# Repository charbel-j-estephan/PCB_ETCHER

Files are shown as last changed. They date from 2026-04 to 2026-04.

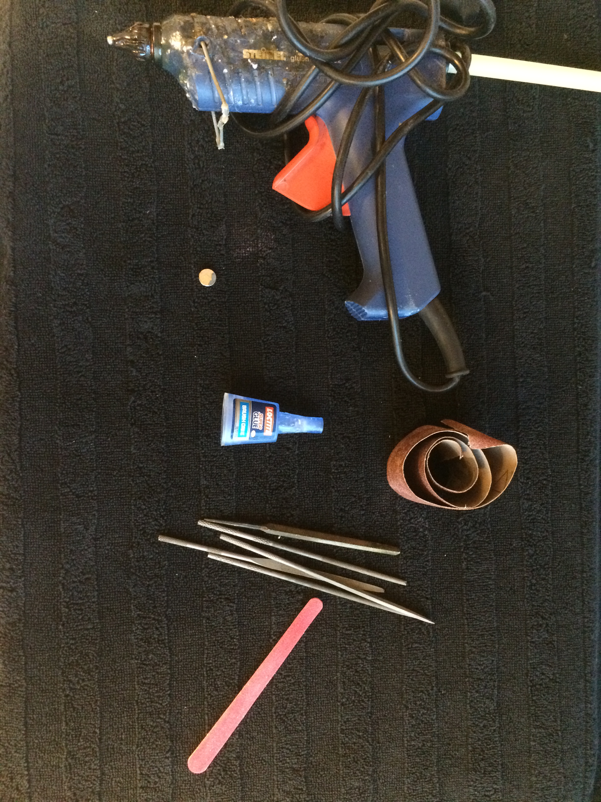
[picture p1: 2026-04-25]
3d prints/servo/images/IMG_0379.JPG

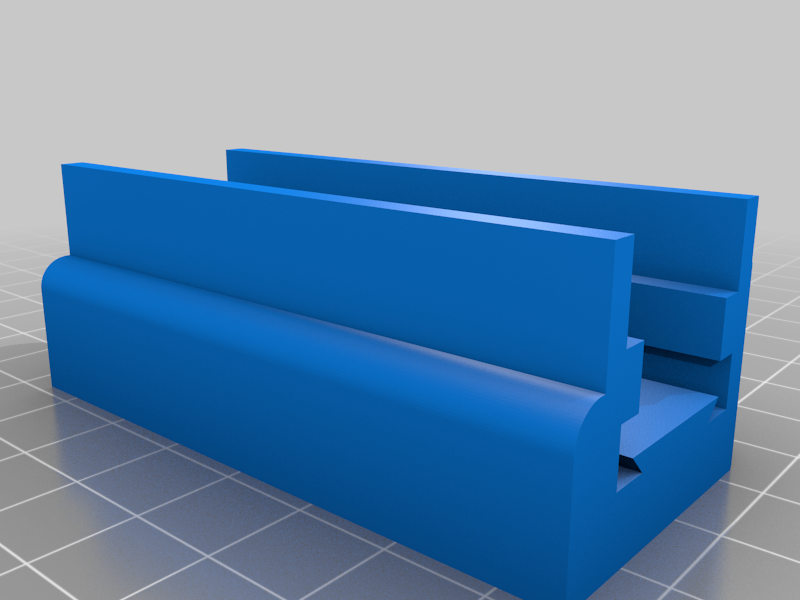
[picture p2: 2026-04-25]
3d prints/servo/images/e4eb49ccf6357d161828037bad2b64a9.png

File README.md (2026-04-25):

# PCB ETCHER

A high-precision automated system designed to convert Gerber files into physical PCB layouts using a **PIC16F877A** for motion control and an **ESP32** for cloud-based file management.

---

## 🚀 Overview
This project bridges the gap between digital PCB design and physical prototyping. It features a custom-built CNC chassis capable of **400 steps/mm precision**, utilizing a frame-based UART protocol for reliable data transfer between the web interface and the motor controllers.

## 🛠️ Technical Specifications

### Hardware
* **Main Controller:** PIC16F877A (Running with a **4MHz Crystal**)
* **Network Bridge:** ESP32 (Web Server & Handshake Protocol)
* **Motors:** NEMA 17 Steppers with T8 Lead Screws
* **Drivers:** L293D H-Bridge with 74HC04 Logic Inverters
* **Actuator:** SG90 Servo for Pen Lift (PWM controlled)
* **Display:** 16x2 LCD (Port E: RS=RE2, RW=RE1, E=RE0)

### Software & Firmware
* **Motion Logic:** Custom implementation of the **Bresenham Algorithm** for linear interpolation.
* **Communication:** UART @ 9600 Baud with a custom frame-based handshake protocol.
* **Microstepping:** Calibrated for 1/16 microstepping.
* **Logic:** * `1` = Pen Down (Writing)
  * `0` = Pen Up (Moving)

## 📂 Project Structure
As shown in the repository:
* `3d prints/` - STL files for the CNC chassis and motor mounts.
* `asm/` - PIC16F877A Assembly source code and firmware.
* `documentations/` - Datasheets, wiring diagrams, and project notes.
* `esp32_firmware_v8_1/` - ESP32 source code for the Wi-Fi bridge.
* `pcb-plotter-server/` - Web interface and Gerber processing logic.
* `simulations/` - Proteus and circuit simulation files.

## 📐 Calibration Details
| Parameter | Value |
| :--- | :--- |
| **Resolution** | 400 steps/mm |
| **Step Angle** | 1.8° |
| **Lead Screw Pitch** | 8mm |
| **Microstepping** | 1/16 |
| **Baud Rate** | 9600 |

## 🏗️ System Architecture
1. **Web UI:** Users upload Gerber files to the `pcb-plotter-server`.
2. **Data Processing:** The ESP32 processes the coordinates and initiates a handshake with the PIC.
3. **Motion Execution:** The PIC16F877A receives instructions and generates precisely timed pulses for the NEMA 17 motors using Assembly-optimized routines.
4. **Homing:** Integrated hardware homing ensures a consistent zero-point.

---

## 🤝 Contributing
Feel free to fork this repo and submit pull requests for any optimizations in the motion algorithm or UI.

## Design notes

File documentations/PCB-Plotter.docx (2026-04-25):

CNC PCB PLOTTER

Design, Firmware & Cloud-Integrated Motion Control

Micro-Controller Lab : PIC 16F877A

Charbel Estephan 20231222
Habib Bou Maroun 20223435

# Abstract

This report documents how to designed and built a CNC PCB plotter from scratch. The machine takes a Gerber file (the standard format that PCB manufacturers use) and draws the copper traces directly onto a blank copper board using a pen. The whole thing runs autonomously once you upload the file from a browser.

The system has three main parts talking to each other: A Python backend running on Google Cloud that converts the Gerber file into machine specific instruction set, an ESP32 that handles WiFi and the webpage, and a PIC16F877A microcontroller written in assembly that actually drives the stepper motors. The PIC is doing all the real-time work from running a Bresenham line algorithm in 24-bit integer arithmetic to generating step pulses at up to 1000 Hz, and maintaining the coordinate system. The motors run at 1/16 micro-stepping through A4988 driver modules, giving a resolution of 400 steps/mm on both axes.

# 1. Introduction

## 1.1 Why Build This

Getting a PCB made professionally takes at least a week and only makes sense if you order several at a time. On the other hand, doing toner transfer at home is messy. A plotter seemed like the right middle ground: it draws the resist mask directly onto the board under numeric control.

It is also a genuinely interesting engineering problem. To make it work you need motion control, embedded firmware, wireless communication, cloud deployment, and mechanical design all working together. Every single part of the stack is under direct control, which made debugging painful at times but also made it very educational.

## 1.2 Goals

A few concrete targets before starting:

- The machine should accept Gerber files because every PCB CAD tool exports Gerber.
- The working area should be at least 250 mm × 220 mm, large enough for most single-sided hobby boards.
- It should be controllable from a browser. No installing software, no USB cable required to start a job.
- Gerber parsing should not happen on the microcontroller. That keeps the embedded firmware small and lets me fix parser bugs without reflashing hardware.

# 2. System Architecture

The plotter is split into three layers, each running on a different processor. The split is not arbitrary, it follows the natural boundary between what needs to be fast, what needs to be smart, and what needs to be heavy.

## 2.1 The Three Layers

### Layer 1 — Cloud Backend (Python / Flask / Google Cloud Run)

Gerber parsing lives here. The backend is a Flask app running in a Docker container on Cloud Run. When the ESP32 uploads a Gerber file, the backend parses it, expands pad geometry into filled pen strokes, clamps everything to the machine's working envelope, and sends back a stream of 14-byte motion commands.

Why Cloud Parsing?
Gerber files can be hundreds of kilobytes, and building a robust Gerber parser in C on a memory-constrained embedded processor is a terrible idea. Python's regex handles the file in milliseconds no hardware involved.

### Layer 2 — Communication Hub (ESP32 / Arduino C++)

The ESP32 is the network interface. It hosts the web page, uploads Gerber to the cloud over HTTPS, fetches the motion commands back in chunks, and relays them one at a time to the PIC over a UART link. In essence it is a protocol translator: WiFi/TLS on one side, simple 9600-baud UART on the other.

### Layer 3 — Motion Controller (PIC16F877A / MPASM Assembly)

The PIC does the real-time heavy lifting. It receives ASCII motion frames, converts them to step counts, runs the Bresenham algorithm to generate coordinated XY pulses, drives the stepper driver modules, polls the limit switches during homing, and updates the LCD. Everything is written in MPASM assembly, because the PIC at 4 MHz has tight timing constraints and the arithmetic needs to be verified at the instruction level when things go wrong.

Layer | Processor | Language | Main job
1 - Backend | Cloud Run | Python / Flask | Gerber parsing, coordinate generation
2 - Hub | ESP32 | Arduino C++ | WiFi, TLS, UART bridge
3 - Motion | PIC16F877A @ 4 MHz | MPASM Assembly | Bresenham, step pulses, LCD display

## 2.2 How a Plot Job Flows

Here is what actually happens end-to-end when you press 'Start' in the browser:

- The user selects a Gerber file in the ESP32's web interface.
- The ESP32 opens a TLS connection to Cloud Run and streams the file as a chunked HTTP upload.
- Cloud Run parses the file, expands all pad geometry, clamps coordinates to 250×220 mm, and writes the result to a temp file. It returns a JSON ticket: {job_id, total_cmds, total_bytes}.
- The ESP32 then fetches the command stream in 4 kB slices via GET /fetch?job=…&offset=…
- Each 14-byte frame is forwarded to the PIC over UART2. The ESP32 waits for ACK before sending the next one.
- After the last frame, the ESP32 sends DELETE /job/<id> to clean up the temp file on the server.

# 3. Hardware Components

## 3.1 PIC16F877A — Motion Controller

The PIC16F877A is the motion controller. It drives the steppers, reads limit switches, handles UART communication with the ESP32, and runs the LCD. It is an 8-bit Harvard RISC processor running at 4 MHz deliberately underpowered by modern standards, which forces you to be intentional about every instruction you write.

## 3.2 ESP32 — Communication Hub

The ESP32 DevKit v1 handles all the networking. It runs at 240 MHz with 520 kB SRAM, supports 802.11 b/g/n WiFi natively, and has a proper TLS stack (Mbed TLS) baked into the SDK. It also has UART2 for the PIC link.

## 3.3 NEMA 17 17HS3401S — Stepper Motors

Both axes use a NEMA 17 17HS3401S bipolar stepper. This is effectively the standard motor for home-scale CNC and 3D printing (it is physically large enough to move a pen carriage smoothly, and supported by every driver, coupler, and mechanical mount on the market). The 17HS3401S specifically is a short-body, low-current variant which keeps heat manageable when the driver is set to around 1.3 A per phase.

Parameter | Value
Step angle | 1.8° (200 full steps/revolution)
Phase current (rated) | 1.3 A
Holding torque | 28 N·cm
Shaft | T8- screw
Body length | 34 mm

The T8 is an 8 mm diameter trapezoidal lead screw with a 4-start thread giving 8 mm of linear travel per revolution. Combined with the 200-step motor and 1/16 micro-stepping: (200 × 16) ÷ 8 = 400 steps per millimeter. That is 2.5 µm per micro-step on paper about 160× finer than the pen tip, so the electronics are never the limiting factor on print quality.

# 4. The Stepper Motor Driver — How It Actually Works

This section goes into more depth than the rest of the report because the stepper driver is the most misunderstood part of the system. Most descriptions of CNC projects say 'connect STEP and DIR to the driver and it works' which is true, but gives you no understanding of what the driver is doing or why the motor behaves the way it does. This section explains the full picture.

## 4.1 The Problem the Driver Solves

Stepper motors are driven by current, not voltage. The torque a stepper produces is proportional to the current flowing through its coils not to the voltage applied. If you just connect a 12V supply directly to the motor windings, the current would ramp up at a rate of V/L (voltage divided by winding inductance, typically 2–5 mH), quickly exceed the rated current, and saturate the iron core, destroying the motor or the driver or both.

The other problem is that generating micro-stepping waveforms in software on the PIC is not feasible. At 1/16 micro-stepping and 1000 Hz step rate, the PIC would need to switch four H-bridge transistors, regulate current on two coils simultaneously, and compute the correct sinusoidal current level — all at 16,000 times per second. At 4 MHz that is 250 instruction cycles per step. There is no room left for Bresenham, UART, or the LCD.

A dedicated driver IC solves both problems. It accepts simple STEP and DIR pulses from the PIC, handles all H-bridge switching and current regulation internally, and operates its power stage from 12V while presenting a 3–5V logic interface. The PIC just counts steps.

| The fundamental role of the driver: translate digital step pulses from a microcontroller running at logic levels into precisely regulated current waveforms in the motor coils at power levels the microcontroller could never handle directly.

## 4.2 Inside the A4988

The A4988 from Allegro Microsystems is a DMOS microstepping driver with built-in translator logic. It is the most commonly used stepper driver in desktop CNC and 3D printing equipment. Understanding it requires understanding five things that happen inside the chip simultaneously.

### 4.2.1 The Translator Logic

The translator is the block that takes STEP pulses and converts them into the correct H-bridge switching pattern. Every rising edge on the STEP pin advances an internal state machine by one position. The state machine drives two full H-bridges — one per motor phase — according to a predetermined sequence.

Without micro-stepping, the sequence follows the classic four-phase pattern (A+B+, A-B+, A-B-, A+B-). With 1/16 micro-stepping enabled, the translator instead steps through a 32-entry lookup table on each STEP pulse, outputting a different target current level for each phase at every position. This is completely invisible to the PIC — it just keeps pulsing STEP and the translator handles the rest.

### 4.2.2 The PWM Chopper — Current Regulation

The lookup table outputs a target current level, but something has to actually enforce that current in the real motor coil. That is what the PWM chopper does. It runs a continuous feedback loop at approximately 20–40 kHz:

- The H-bridge applies 12V across the motor coil. Current ramps up at a rate of V/L (roughly 2–4 A/ms for the 17HS3401S).
- A small sense resistor (R_sense, soldered on the breakout board) is in series with the coil. The voltage across it equals I × R_sense and is read by an internal comparator.
- When the sensed current reaches the target level from the lookup table, the comparator fires and the PWM latch cuts off the H-bridge.
- After a fixed off-time (set by external components, typically 20–40 µs), the bridge re-enables and the cycle repeats.

The net result is a sawtooth current waveform whose average value equals the target level from the table. The 12V supply charges the coil quickly and the chopper regulates the average — this is why the motor runs from 12V even though its rated voltage is only 2.8V. Higher supply voltage means faster current rise, which means more torque at speed.

| The fixed off-time chopper is the reason CNC motors run from a much higher voltage than their rated spec. The driver is not applying 12V DC to a 2.8V motor — it is using 12V to charge the coil inductance quickly, then chopping the current back to the rated level. The result is better high-speed torque compared to running at 2.8V directly.

### 4.2.4 The H-Bridge — How Current Direction Works

A bipolar stepper needs current to flow in both directions through each winding to complete full rotation. A single transistor cannot do this — you need an H-bridge, which is four switching elements arranged so current can flow either way:

+12V

[FET1] [FET3] ← high-side (P-channel DMOS)

+---M---+ ← motor winding between midpoints

[FET2] [FET4] ← low-side (N-channel DMOS)

GND / R_sense

Forward current: FET1 + FET4 ON, FET2 + FET3 OFF

Reverse current: FET3 + FET2 ON, FET1 + FET4 OFF

The A4988 contains two complete H-bridges — one for Phase A (coils 1A/1B) and one for Phase B (coils 2A/2B). The translator logic switches these bridges in the correct sequence as STEP pulses arrive. The PIC never needs to think about any of this.

## 4.3 Setting the Current — VREF Explained

This is the most important calibration step and the one most likely to go wrong if you do not understand what you are doing. The maximum phase current is set by a trim potentiometer on the breakout board, which sets a reference voltage on the VREF pin of the IC. The relationship is:

A4988 formula: I_max = VREF / (8 × R_sense)

A4988 module (R_sense = 0.068 Ω), target I = 1.1 A:

VREF = 1.1 × 8 × 0.068 = 0.598 V → set to ~0.6 V

To calibrate: power the board without the motor connected, touch a multimeter positive probe to the VREF test point (centre of the trim pot), negative to GND, and adjust until you reach the target voltage. Do not skip this step — VREF too high will cook the driver; too low and the motor misses steps under load.

| Important: always attach the small aluminium heatsink to the top of the IC before running at currents above about 0.5 A. At 1.1 A per phase the driver dissipates roughly 1.5–2 W. Without a heatsink the thermal protection trips at ~150°C junction temperature, causing random shutdown that looks like firmware bugs.

## 4.4 Micro-Stepping Mode Selection

The micro-stepping resolution is set by three logic pins: MS1, MS2, MS3. On the breakout board, pull-up resistors hold all three HIGH by default (1/16 mode). The truth table is:

MS1 | MS2 | MS3 | Mode | Steps/rev | Steps/mm on T8
LOW | LOW | LOW | Full step | 200 | 25
HIGH | LOW | LOW | Half step | 400 | 50
LOW | HIGH | LOW | Quarter step | 800 | 100
HIGH | HIGH | LOW | Eighth step | 1,600 | 200
HIGH | HIGH | HIGH | Sixteenth step | 3,200 | 400

In this project all three MS pins are left floating to their board pull-ups (all HIGH), so the driver is always in 1/16 mode. No wiring from the PIC to the MS pins is needed. The PIC firmware assumes 400 steps/mm at all times.

## 4.5 A4988 vs DRV8825 — Which One and When

I started the project with the A4988 during full-step testing and switched to the DRV8825 when moving to 1/16 micro-stepping. Both modules are pin-compatible so swapping them required zero firmware changes. The practical differences that affected this project:

Feature | A4988 | DRV8825 | Notes
Max phase current | 2.0 A | 2.5 A | Both fine at 1.1 A — DRV8825 has more headroom
Max micro-stepping | 1/16 | 1/32 | DRV8825 is a future upgrade path
Step pulse minimum | 1 µs | 1.9 µs | PIC generates ~4 µs pulses — both satisfied
Current formula | VREF/8Rs | VREF/2Rs | Must not confuse these when setting VREF
Mid-band noise | More | Less | DRV8825 runs noticeably quieter at 1/16
Cost | Cheaper | Slightly more | Small difference at these quantities

## 4.6 Wiring the Driver to the PIC

The interface between PIC and driver uses four wires: two per axis (STEP and DIR). Both the A4988 and DRV8825 accept 3–5.5V / 2.5–5.25V logic, so the PIC's 5V outputs connect directly with no level shifting needed.

Driver Pin | PIC Pin | Signal | Notes
STEP (X axis) | PORTB,0 | X_STEP | Each rising edge = one micro-step
DIR (X axis) | PORTB,1 | X_DIR | Set before first STEP pulse; hold for entire move
STEP (Y axis) | PORTB,2 | Y_STEP | Same as X
DIR (Y axis) | PORTB,3 | Y_DIR | Same as X
ENABLE | GND | ~ENA | Tie permanently LOW — always enabled
RESET | 5V | ~RST | Tie permanently HIGH — never reset mid-job
MS1/MS2/MS3 | (pull-up) | Mode | Left to board pull-ups → 1/16 mode, no PIC wiring needed
VMOT | 12V PSU | Power | 100 µF 35V electrolytic cap to GND required nearby
1A, 1B | Motor coil A | Phase A | Polarity sets forward direction
2A, 2B | Motor coil B | Phase B | Polarity sets forward direction

The 100 µF decoupling capacitor on VMOT is not optional. The chopper generates sharp current spikes each switching cycle; without the capacitor these produce voltage spikes on the supply rail that can exceed the driver's absolute maximum rating and destroy it. I learned this the hard way on the first driver module.

### Step Pulse Generation in Firmware

On the PIC side, each step is generated by a brief BSF/BCF pair on the PORTB pin:

; Generate one step pulse on the X axis

BSF PORTB, 0 ; STEP → HIGH (rising edge triggers step in driver)

NOP ; short hold — A4988 needs ≥1 µs, DRV8825 ≥1.9 µs

NOP ; at 4 MHz each NOP = 250 ns; four NOPs = 1 µs minimum

NOP

NOP

BCF PORTB, 0 ; STEP → LOW (ready for next pulse)

; After this, STEP_DELAY loop runs to set the inter-step gap (feed rate)

The DIR pin must be stable before the first STEP pulse. In the Bresenham implementation, XDIR_F and YDIR_F flags are set based on an explicit compare of target vs. current position before entering the motion loop — so the direction is locked in before any pulses are generated.

## 4.7 Why 1/16 Micro-Stepping Made Such a Difference

The upgrade from full-step to 1/16 micro-stepping was the single most impactful change in the entire project in terms of visible output quality. The differences were immediate and obvious:

- Diagonal lines: at full-step you can see a faint staircase pattern on 45-degree traces. At 1/16 they look perfectly straight.
- Noise: the motor went from a loud resonant whine to a soft hiss. The resonance frequency at full-step falls right in the audible range at typical CNC feed rates; micro-stepping shifts it high enough that the motor passes through it too quickly to excite it.
- Vibration: at full-step you can feel the table vibrating during a move. At 1/16 it is essentially smooth. This matters for line quality because vibration means pen wobble.

The cost is that the PIC has to generate 16× more step pulses for the same linear travel. At 40 mm/s and 400 steps/mm, that is 16,000 pulses per second. At 4 MHz, one pulse every 250 instruction cycles is tight but workable — the Bresenham inner loop plus step pulse plus minimum delay fits in that window with a small margin.

# 5. Firmware Architecture

## 5.1 PIC16F877A — MPASM Assembly

### 5.1.1 Main Loop

The PIC firmware is a single-threaded assembly program. After initialisation and homing it drops into a tight loop that repeats for every motion command:

MAIN

CALL RECEIVE_LINE ; wait for a 14-byte ASCII frame on UART

BTFSC ENDFLAG, 0 ; is it the 'END' marker?

GOTO PLOT_DONE ; yes → stop and print PLOT COMPLETE

CALL PARSE_AND_DISPLAY ; unpack X, Y, pen; update LCD

CALL EXECUTE_MOTION ; Bresenham + step pulses

CALL SEND_ACK ; send 'A' back to ESP32

GOTO MAIN

### 5.1.2 Peripheral Init (what each register actually does)

- TRISC = 0x81: makes RC7 (UART RX) an input and RC6 (TX) an output. The asymmetric pattern is because the USART overrides the TX TRIS bit automatically, but not RX.
- TXSTA = 0b00100100: selects asynchronous 8-bit mode, BRGH=1 for high-speed baud rate generation.
- SPBRG = 25: with BRGH=1 and Fosc=4 MHz, gives 4,000,000 ÷ (16×26) = 9,615 baud (+0.16% error — well within UART tolerance).
- RCSTA = 0b10010000: enables the serial port (SPEN) and the receiver (CREN).
- ADCON1 = 0x06: disables the ADC on all pins, reclaiming PORTA and PORTE as pure digital I/O.
- CMCON = 0x07: disables the comparators, which otherwise interfere with limit switch reads on PORTA.
- TRISA = 0b00001100: keeps PORTA,2 and PORTA,3 as inputs for the X and Y limit switches.

### 5.1.3 Memory Map (relevant registers)

Address | Name | What it holds
0x30–0x3D | BUF[14] | The current incoming ASCII frame
0x50–0x55 | XTGT / YTGT | Target position, 24-bit, 3 bytes each
0x56–0x5B | XCUR / YCUR | Current machine position, 24-bit
0x5C–0x64 | DX / DY / BERR | Bresenham deltas and error accumulator, 24-bit
0x70–0x72 | MULX/MULH/MULL | Result of the step conversion multiply
0x68–0x6A | XDIR_F / YDIR_F / DOM_FLAG | Direction and dominant-axis flags

## 5.2 The 24-Bit Bresenham Algorithm

This is the core of the motion controller. Coordinated XY motion requires that both axes reach their targets at the same time, tracing a straight line between start and end points. Bresenham's algorithm does this using only integer addition and subtraction — no floating point, no trigonometry, which is essential on a processor with no hardware multiplier.

DX = |x_target - x_current|

DY = |y_target - y_current|

if DX >= DY:

dominant = X, minor = Y

else:

dominant = Y, minor = X

BERR = D_dominant / 2 ← starting error (biased to centre)

loop D_dominant times:

step dominant axis

BERR -= D_minor

if BERR < 0:

step minor axis

BERR += D_dominant

The 24-bit implementation is needed because step counts at 1/16 micro-stepping reach up to 100,000 (250 mm × 400 steps/mm), which overflows 16-bit integers. Every arithmetic operation on the three-byte values requires explicit carry propagation. The critical pattern:

; Add two 24-bit numbers stored as (HI:MD:LO) byte triples

ADD24:

MOVF TMP3, W

ADDWF RES_LO, F ; add low bytes

BTFSC STATUS, C ; did it carry into middle?

INCF RES_MD, F ; yes → bump middle byte

BTFSC STATUS, Z ; did that INCF roll over to zero?

INCF RES_HI, F ; yes → bump high byte too

MOVF TMPL, W

ADDWF RES_MD, F

BTFSC STATUS, C

INCF RES_HI, F

MOVF TMPH, W

ADDWF RES_HI, F

RETURN

The double-check (BTFSC STATUS,C then BTFSC STATUS,Z) is the key insight. The first catches the carry from the ADDWF. The second catches the case where the INCF of the middle byte itself rolls from 0xFF to 0x00 — which sets the Zero flag, not the Carry flag. Missing this second check causes a carry loss bug that manifests as coordinates being exactly 65,536 steps short. I hit this bug and spent a long time finding it.

## 5.3 ESP32 State Machine

The ESP32 loops through states: IDLE → SENDING (upload to Cloud Run) → READING_JOB (parse ticket JSON) → FETCH_CONNECT / FETCH_BODY (get next chunk) → PLOT_CHUNK (forward frames to PIC) → WAITING_ACK (blocked on PIC response) → CLEANUP → DONE. Each TLS session is closed after one 4 kB chunk to avoid Cloud Run idle timeout.

## 5.4 Flask Backend

The backend is about 390 lines of Python. The three endpoints are POST /convert (parse Gerber, return job ticket), GET /fetch?job=&offset=&len= (serve a byte slice), and DELETE /job/<id> (clean up). The Gerber divisor is extracted at runtime from the %FSLAX/Y header: divisor = 10^(number of decimal digits). Final frame format: f"I{x:06d}{y:06d}{pen}" — 14 characters, always, asserted before return.

# 6. Communication Protocol

## 6.1 Frame Format

Every motion command is a 14-byte ASCII string terminated by a single LF:

I XXXXXX YYYYYY Z \n

I = 1 byte = start marker, always the literal character 'I'

XXXXXX = 6 bytes = X position in steps, zero-padded ASCII decimal

YYYYYY = 6 bytes = Y position in steps, zero-padded ASCII decimal

Z = 1 byte = pen state: '1' = down, '2' = up

\n = 1 byte = line feed terminator

End-of-stream: the literal string END\n

Example: I0012000005001\n

X = 1200 steps = 3.00 mm, Y = 500 steps = 1.25 mm, pen down

## 6.2 Why ASCII and Not Binary

An early version of the protocol used binary encoding: one command byte, two 16-bit little-endian coordinate fields, one ACK byte. It was about half the size on the wire. I replaced it because it was genuinely unpleasant to debug — a single dropped byte on a binary stream corrupts every subsequent frame silently, and diagnosing that on a 9600-baud logic analyser trace is not fun.

ASCII with a fixed start marker ('I') and newline terminator is self-synchronising. The PIC can always find the next valid frame by scanning for 'I' followed by 12 digits and a valid pen byte. At 9600 baud and roughly one command per millimetre of travel, the extra bytes cost nothing measurable — the link never even approaches saturation.

## 6.3 Flow Control

Strict stop-and-wait: the ESP32 sends one frame, then waits for the PIC's two-byte response (pen-state echo + 'A' for ACK, or 'R' for NAK / retransmit). The important thing is that this is applied against a streaming data source — the ESP32 has the next frame ready to write the moment ACK arrives, so from the motor's perspective successive frames arrive without any meaningful gap. This is what prevents ink blobs at corners. More detail in Section 8.1.

# 7. Gerber Processing Pipeline

## 7.1 What Is a Gerber File

Gerber (RS-274X) is the format PCB manufacturers use. It is a text file describing shapes using a small command set: FS (coordinate format declaration), MO (units), AD (aperture definition), and operation codes D01/D02/D03 (draw/move/flash). The first thing the parser does is read the FS header to determine the coordinate divisor, which varies between files:

FS header | Decimal digits | Divisor | Example: X100000 =
%FSLAX24Y24*% | 4 | 10,000 | 10.0 mm
%FSLAX36Y36*% | 6 | 1,000,000 | 0.1 mm
%FSLAX46Y46*% | 6 | 1,000,000 | 0.1 mm

Getting this wrong was one of my early bugs — the parser was using a hardcoded divisor of 10,000 when most modern Gerbers need 1,000,000. The board was drawn at 1/100th scale. The fix was extracting the divisor from the header at runtime using a regex.

## 7.2 Aperture Expansion

When the Gerber file places a pad (D03 command), the parser does not just draw a dot — it expands the pad shape into a series of filled pen strokes using a 0.2 mm raster step (half the 0.4 mm pen width). Three shapes are handled:

- Circles: boundary stroke + horizontal raster + vertical raster. Both raster directions ensure complete coverage even with a worn pen tip.
- Rectangles: double boundary pass (to sharpen edges) + both-axis raster fill.
- Obrounds (stadium pads): boundary along the exact curved outline + serpentine fill within the stadium shape.

## 7.3 Coordinate Output

After all coordinates are collected: translate so the minimum corner sits at (0,0), mirror X if needed for copper-side-up drawing, add a 2 mm safety margin on both axes, then multiply by 400 to get integer step counts. The server also enforces a MAX_X_MM = 250 / MAX_Y_MM = 220 hard limit and returns HTTP 400 if the board is too large, with a message the web UI shows directly to the user.

# 8. Bugs and How I Fixed Them

This section is probably the most useful part of the report from a technical understanding perspective. These are the significant bugs I found and fixed during development. In each case I describe what was happening, why it was happening, and exactly what changed.

## 8.1 Ink Blobs at Every Corner

Symptom: every polygon corner on the drawn output had a small but visible ink blob, as if the pen had rested on the board for a moment before changing direction — because it had.

Root cause: the original protocol was strict stop-and-wait. The ESP32 sent a command, the PIC executed it from a standstill, the motor stopped completely, the PIC replied DONE, and only then did the ESP32 prepare and send the next command. Every direction change caused a full decelerate-halt-accelerate cycle, giving the pen a fraction of a second to sit stationary on the board and transfer extra ink via capillary action.

Fix: the protocol was redesigned so the ESP32 has the next frame already waiting in its UART transmit FIFO by the time the PIC's ACK arrives. Because 9600 baud transmission is fast relative to motor motion, the PIC receives the next command before the motor has fully stopped. From the motor's perspective, successive frames are continuous. The blobs disappeared completely.

## 8.2 24-Bit Carry Loss (the Hard One)

Symptom: plots of boards taller than about 163 mm would fail near the top. The Y carriage would stop 65,536 steps short of its target, crash into the mechanical end stop, and the plot would halt.

Root cause: 163 mm × 400 steps/mm = 65,200 steps, which is just under the 16-bit limit (65,535). Any Y coordinate above that required the middle byte of the 24-bit step count to roll over from 0xFF to 0x00. When that INCF executes, it sets the Zero flag — not the Carry flag — on the PIC. My carry propagation code only checked STATUS,C, so the carry into the high byte was silently dropped. Every Y coordinate above 163 mm was calculated as exactly 65,536 steps too small.

Fix: added a second check after every middle-byte INCF:

BTFSC STATUS, C ; carry from the previous ADDWF?

INCF MULH, F ; yes → increment middle byte

BTFSC STATUS, Z ; did that INCF roll MULH to 0x00?

INCF MULX, F ; yes → carry must propagate to high byte

This second BTFSC STATUS,Z / INCF pair is the bit I was missing everywhere. After adding it consistently to all 24-bit arithmetic blocks, the full coordinate range worked correctly.

## 8.3 Multiply-by-25 Was Multiply-by-5

Symptom: with the full-step firmware (25 steps/mm), every move was exactly 1/5 of the commanded distance. Commanding 100 mm produced 20 mm of travel.

Root cause: the shift-add multiplier for 25 (binary 11001) was missing the 8× shift term. The routine was computing 16× + 1× = 17×, and a second bug made it actually compute 4× + 1× = 5×. Fix: rewrote the routine from scratch against binary 11001 (bits 0, 3, 4), verified against Python for all inputs 0–65,535.

## 8.4 MUL8×16 High-Byte Corruption

Symptom: after the ×25 fix, moves over ~50 mm overshot by seemingly random amounts. Root cause: the carry-propagation in the multiplier used ADDLW to add 1 to W before adding to the high byte. ADDLW modifies W — so on the next iteration, W no longer held the multiplier byte as expected. Fix: replaced ADDLW/ADDWF with INCF (which never touches W), and added an explicit MOVF to reload the multiplier byte before each ADDWF.

## 8.5 Gerber Divisor (Drawings 100× Too Small)

Symptom: first real Gerber file drawn at 1/100th scale — the layout was recognisable but tiny. Root cause: hardcoded divisor of 10,000; the file used %FSLAX46Y46% which needs 1,000,000. Fix: runtime regex extraction of divisor = 10^(decimal field width) from the FS header.

## 8.6 Bresenham Direction Regression

Symptom: a brief firmware revision drew a mirror image along one axis. Root cause: tried to determine direction from the borrow flag of a 16-bit subtraction done as two 8-bit subtracts. Borrow does not propagate to the global carry bit correctly in this arrangement. Fix: reverted to explicit compare of target vs. current position before the loop, storing results in XDIR_F / YDIR_F flags. More readable and provably correct.

# 9. Testing and Validation

## 9.1 Proteus Simulation

Every significant firmware revision was run in Proteus before being flashed to real hardware. The simulation gives cycle-exact behaviour: the HD44780 virtual module shows the LCD output character-by-character, the virtual UART terminal lets you see exactly what bytes the PIC is receiving and transmitting, and logic analysers on PORTB show the actual step and direction pulses. About 80% of the bugs in Section 8 were found and fixed in simulation — not on hardware.

## 9.2 Step Calibration

Physical calibration: command exactly 100 mm in X and Y against a printed ruler. With 400 steps/mm and the T8 lead screw, the measured travel is within 0.1 mm of the commanded value. This confirms the firmware conversion constants are correct and the lead screw geometry matches the assumed 8 mm/rev lead.

## 9.3 End-to-End Plot Trials

Two regression test files: test_square.gbr (30×30 mm square with circular pads at corners — tests aperture expansion and corner motion) and test.gbr (complex trace pattern with diagonals, obrounds, overlapping polygons). Final validation involved drawing on copper-clad stock with resist-pen ink, etching in ferric chloride, inspecting under magnification, and testing trace continuity with a multimeter.

# 10. Final Specifications

## 10.1 Electrical

Parameter | Value
Motor supply | 12 V DC
Logic supply | 5 V DC (regulated from 12 V)
ESP32 supply | 5 V (on-board linear regulator)
Stepper phase current | ~1.1 A per phase (A4988 VREF ≈ 0.60 V)
UART (ESP32 ↔ PIC) | 9,600 baud, 8N1
WiFi | 2.4 GHz 802.11 b/g/n, WPA2-PSK

## 10.2 Mechanical

Parameter | Value
Work envelope | 250 mm (X) × 220 mm (Y)
Pen tip | 0.4 mm diameter
Raster fill step | 0.2 mm (half pen width)
Safety margin | 2 mm from origin on both axes
Homing | Micro-switch limits on PORTA,2 (X) and PORTA,3 (Y)
Frame material | 3D-printed PLA, 0.2 mm layers, 40% infill

## 10.3 Motion and Resolution

Parameter | Value
Step angle | 1.8° (200 full steps/revolution)
Lead-screw lead | 8 mm/revolution (T8, 4-start)
Micro-step resolution | 400 steps/mm at 1/16 (2.5 µm/step)
Step rate (calibrated) | 1,000 Hz
Feed rate (calibrated) | 2.5 mm/s linear (= 1000 Hz ÷ 400 steps/mm)
Max step count (X) | 100,000 steps (24-bit)
Max step count (Y) | 88,000 steps (24-bit)

# 11. Conclusion

## 11.1 What Was Achieved

The machine works. You can take a Gerber file from KiCad or any other standard PCB tool, upload it through the browser, and the plotter draws it onto copper-clad stock without any further intervention. Line quality is good — corners are clean, diagonals are smooth, and pads are properly filled. All the design goals from Section 1.2 are met.

## 11.2 Things I Would Do Differently

The biggest thing I would change is the communication architecture between the ESP32 and PIC. Using a higher baud rate — 115,200 instead of 9,600 — would allow tighter ACK-response loops and potentially higher feed rates without any firmware complexity cost. I stayed at 9,600 because it was the working value and changing it mid-project felt risky, but in hindsight it is an easy upgrade.

I would also add a proper velocity profile — ramp up from zero, hold constant speed, ramp down before a stop. Right now the motor accelerates instantly from zero, which works but causes occasional missed steps on long diagonal moves that start at full speed. This requires a small look-ahead buffer and is doable in assembly.

# Appendix A — Complete Pin Assignments

## A.1 PIC16F877A

Pin | Port | Dir | Signal | Connected to
33 | PORTB,0 | Out | X_STEP | A4988/DRV8825 STEP (X axis)
34 | PORTB,1 | Out | X_DIR | A4988/DRV8825 DIR (X axis)
35 | PORTB,2 | Out | Y_STEP | A4988/DRV8825 STEP (Y axis)
36 | PORTB,3 | Out | Y_DIR | A4988/DRV8825 DIR (Y axis)
4 | PORTA,2 | In | LIM_X | X limit switch, pull-down, active high
5 | PORTA,3 | In | LIM_Y | Y limit switch, pull-down, active high
25 | PORTC,6 | Out | UART TX | ESP32 GPIO16 (UART2 RX)
26 | PORTC,7 | In | UART RX | ESP32 GPIO17 (UART2 TX)
19–30 | PORTD,0–7 | Out | LCD D0–D7 | HD44780 data bus (8-bit mode)
8 | PORTE,0 | Out | LCD E | HD44780 Enable
9 | PORTE,1 | Out | LCD RW | HD44780 R/W (write only)
10 | PORTE,2 | Out | LCD RS | HD44780 Register Select

## A.2 ESP32 DevKit v1

GPIO | Dir | Signal | Connected to
GPIO16 | In | UART2 RX | PIC PORTC,6 (TX)
GPIO17 | Out | UART2 TX | PIC PORTC,7 (RX)
GPIO23 | Out | Servo PWM | SG90 continuous-rotation servo signal
GND | Pwr | Ground | Common ground with PIC and driver modules

# Appendix B — Firmware Constants

Constant | Value | Where | What it controls
STEPS_PER_MM | 400 | PIC | Steps per mm at 1/16 micro-stepping
SPBRG | 25 | PIC | UART baud rate divisor (→ 9615 baud at 4 MHz)
STEP_DELAY | 1 ms | PIC | Inter-step gap; sets feed rate
MAX_STEPS | 100,000 | PIC | Hard coordinate clamp in firmware
SERVO_STOP | 95 | ESP32 | PWM value that stops the SG90 (calibrate per unit)
SERVO_CW_SPEED | 110 | ESP32 | Pen-UP spin speed
SERVO_CCW_SPEED | 70 | ESP32 | Pen-DOWN spin speed
SERVO_MOVE_MS | 400 | ESP32 | Time to spin between pen states (ms)
ACK_TIMEOUT_MS | 60,000 | ESP32 | Max wait for PIC ACK before error
FETCH_CHUNK_SIZE | 4,096 | ESP32 | Bytes per /fetch request (~270 frames)
MAX_X_MM | 250 | Flask | Work envelope X limit
MAX_Y_MM | 220 | Flask | Work envelope Y limit
FILL_STEP | 0.2 | Flask | Pad raster step in mm
MIRROR_X | True | Flask | Mirror X for copper-side-up plotting

# Appendix C — End-to-End Frame Example

This traces one motion command from Gerber file all the way to physical motor pulses, to show how all the layers connect.

### Gerber input

%FSLAX46Y46*% ; divisor = 1,000,000

%MOMM*% ; metric

X100000Y050000D01* ; raw coords: X=0.10 mm, Y=0.05 mm, pen down

### Flask processing

x_mm = 100000 / 1,000,000 = 0.10 mm

y_mm = 50000 / 1,000,000 = 0.05 mm

Add 2mm margin: x = 2.10 mm, y = 2.05 mm

Convert to steps: x = 2.10 × 400 = 840, y = 2.05 × 400 = 820

pen = '1' (D01 = draw)

Output frame: I0008400008201\n

### ESP32 transmission

Serial2.write("I0008400008201\n", 15);

// 15 bytes at 9600 baud → transmission takes ~15.6 ms

// ESP32 transitions to WAITING_ACK

### PIC reception and motion

RECEIVE_LINE: BUF = ['I','0','0','0','8','4','0','0','0','8','2','0','1','\n']

Validation: start='I' ✓ digits ✓ pen='1' ✓

XTGT = 840, YTGT = 820, PENVAL = '1' (pen down)

EXECUTE_MOTION:

Assume previous position was (0, 0)

DX = 840, DY = 820 → dominant axis = X (840 > 820)

Bresenham runs 840 iterations:

X steps every iteration (840 total)

Y steps when error underflows (820 total)

At 1000 Hz: ~840 ms of motion

SEND_ACK: TX → '1' (pen state echo), 'A' (acknowledge)

### ACK received

ESP32 sees '1' → updates servo state, sees 'A' → returns to PLOT_CHUNK and sends the next frame. Total round-trip dominated by motion time. UART overhead is under 2% of total command time.

CNC PCB Plotter — Engineering Report | Charbel Estephan & Habib Bou Maroun

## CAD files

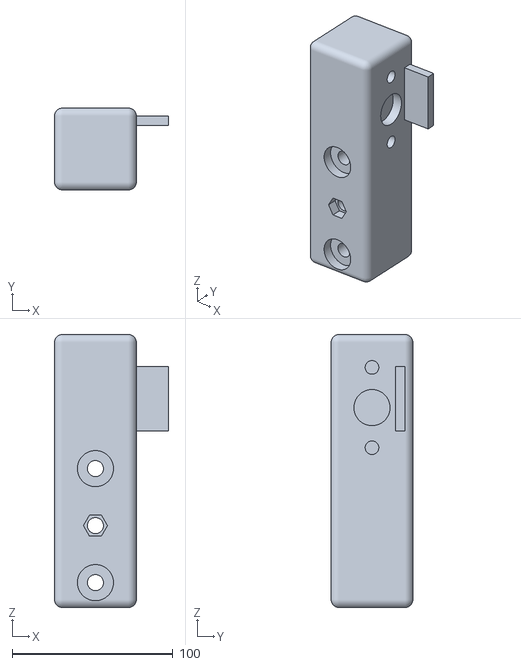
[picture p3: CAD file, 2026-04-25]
3d prints/2-Axis CNC - 5513594/files/Y-Axis_Carriage_W-O_Motor.stl
71.0 x 51.0 x 170.0

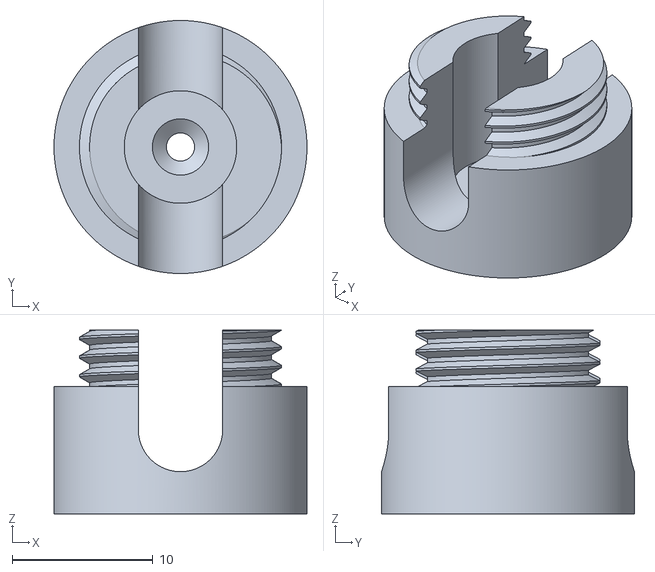
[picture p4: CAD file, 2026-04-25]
3d prints/cable holder/WL_D6.0mm_Bottom.stl
18.0 x 18.0 x 13.1

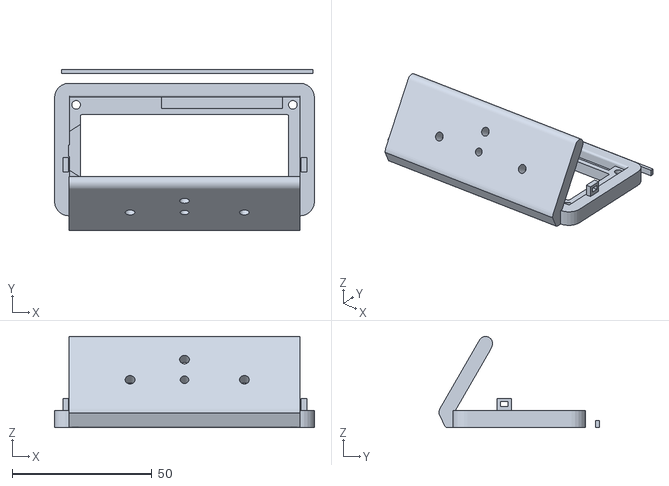
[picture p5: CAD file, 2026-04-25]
3d prints/lcd holder/files/LCD_Screen_Stand_v2.stl
92.9 x 57.4 x 32.6

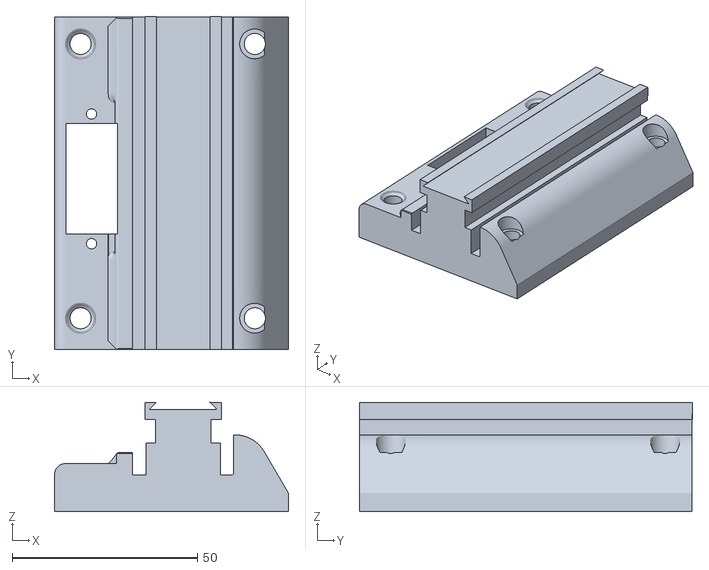
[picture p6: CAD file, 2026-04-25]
3d prints/servo/files/base_v2.0_servo_HS-85MG.stl
63.1 x 89.8 x 29.5

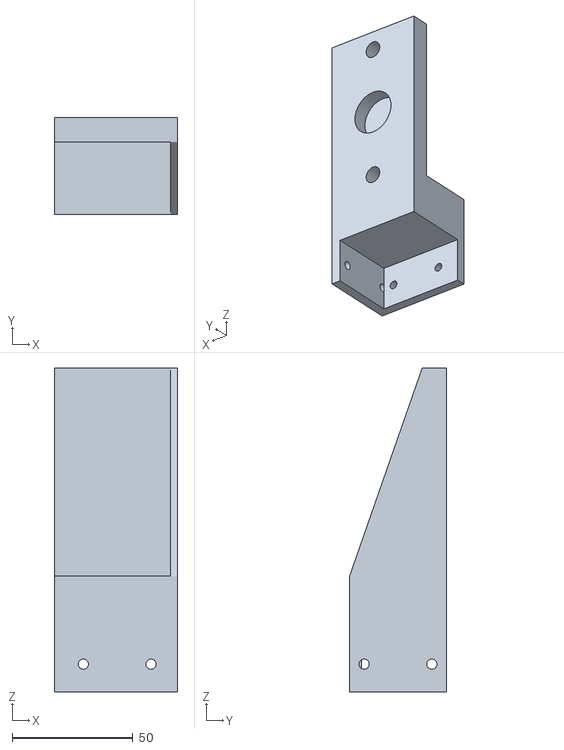
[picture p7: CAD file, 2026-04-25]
3d prints/2-Axis CNC - 5513594/files/Y-Axis_End.stl
51.0 x 40.0 x 134.0

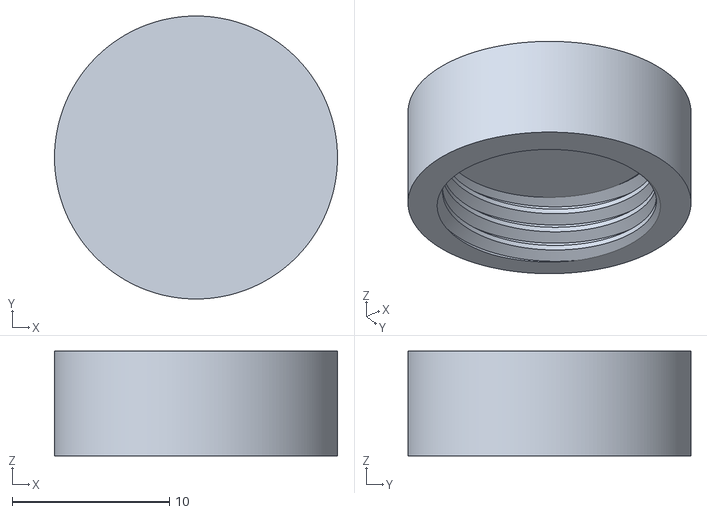
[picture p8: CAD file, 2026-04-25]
3d prints/cable holder/WL_D6.0mm_Top_Smooth.stl
18.0 x 18.0 x 6.67

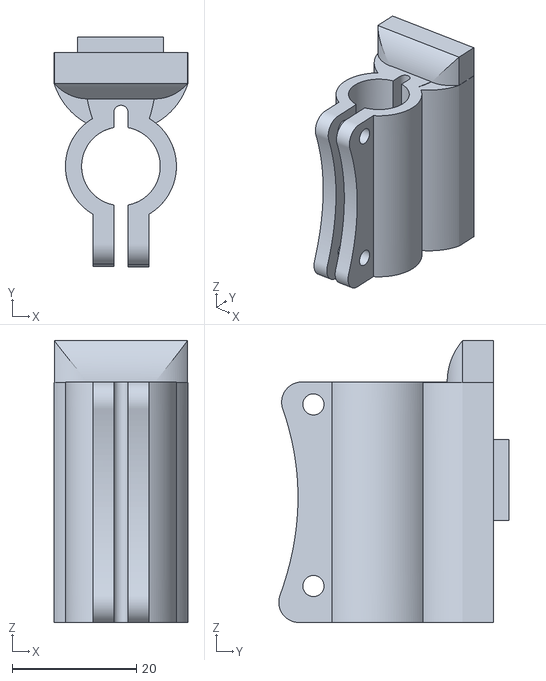
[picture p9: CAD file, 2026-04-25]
3d prints/servo/files/Pen_Mount_v2.0_HS-85MG_12mm_Magnets.stl
21.6 x 37.1 x 45.4

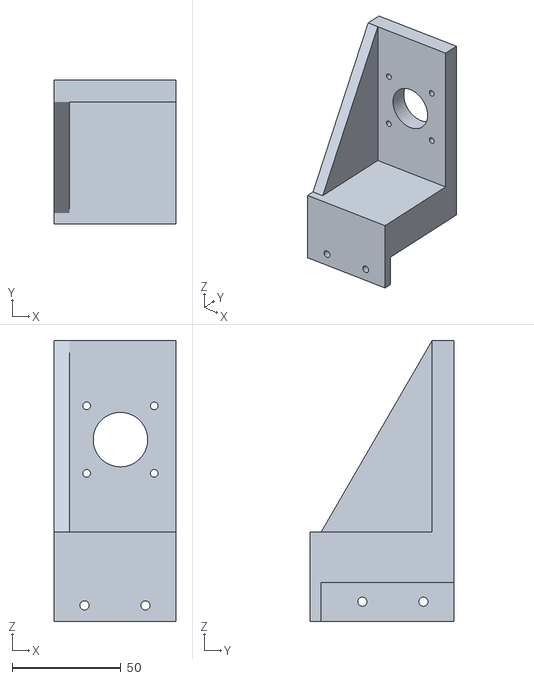
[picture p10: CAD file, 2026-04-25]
3d prints/2-Axis CNC - 5513594/files/Stepper_Motor_Mount.stl
56.0 x 66.0 x 129.0

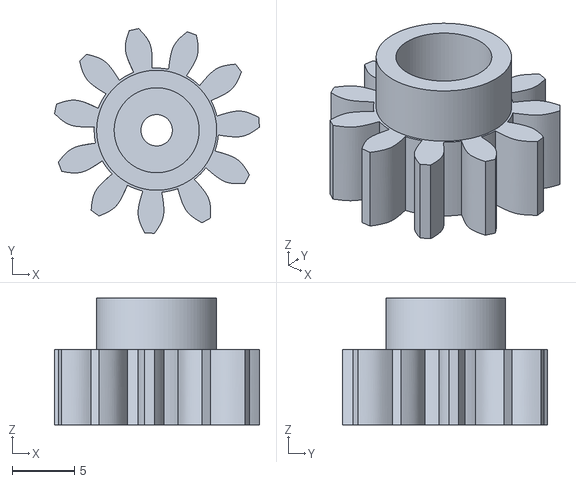
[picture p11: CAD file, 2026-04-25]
3d prints/servo/files/Gear.stl
16.5 x 16.5 x 10.2

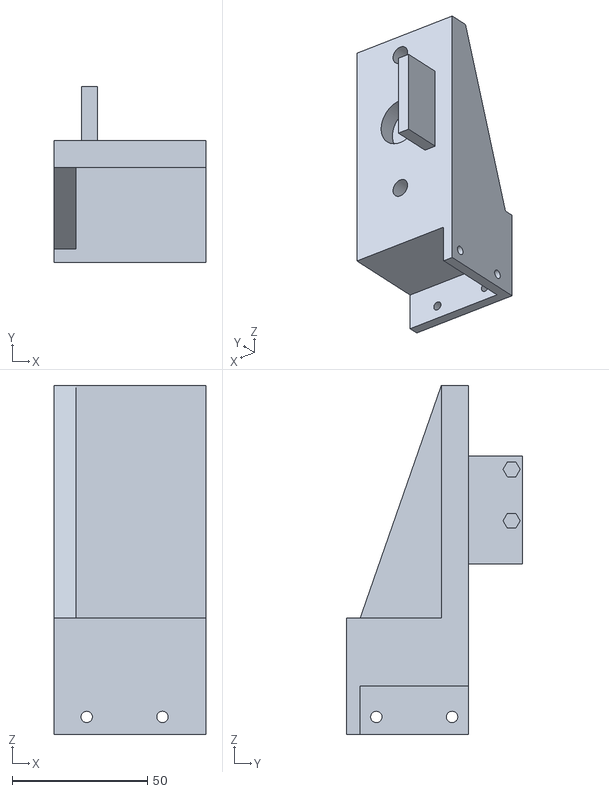
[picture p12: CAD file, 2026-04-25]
3d prints/2-Axis CNC - 5513594/files/Y-Axis_End_2.stl
56.0 x 65.0 x 129.0

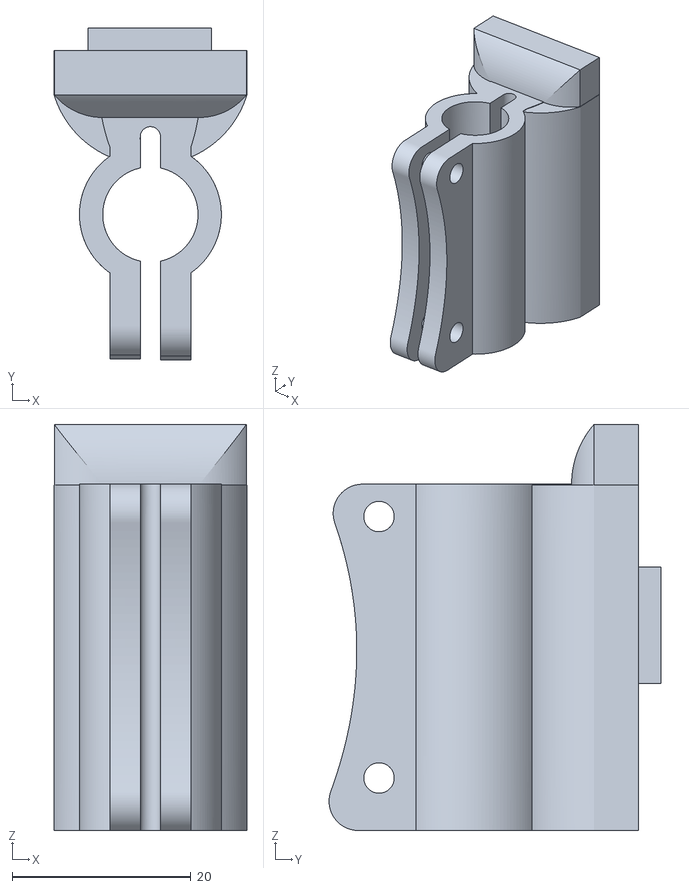
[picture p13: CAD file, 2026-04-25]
3d prints/servo/files/Pen.stl
21.6 x 37.1 x 45.4

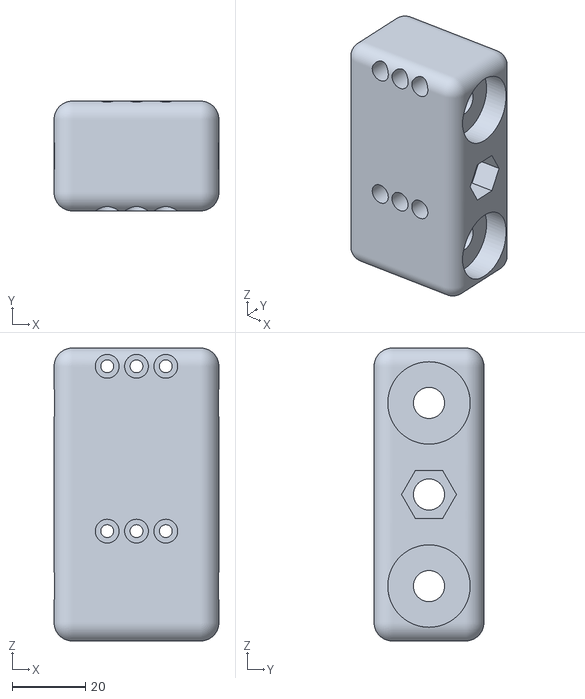
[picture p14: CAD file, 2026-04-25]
3d prints/2-Axis CNC - 5513594/files/Laser_Attachment.stl
45.0 x 30.0 x 80.0

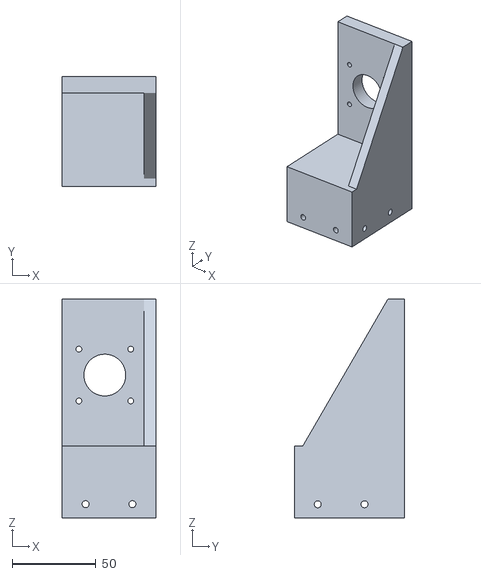
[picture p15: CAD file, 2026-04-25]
3d prints/2-Axis CNC - 5513594/files/Stepper_Motor_Mount_2.stl
56.0 x 66.0 x 131.0

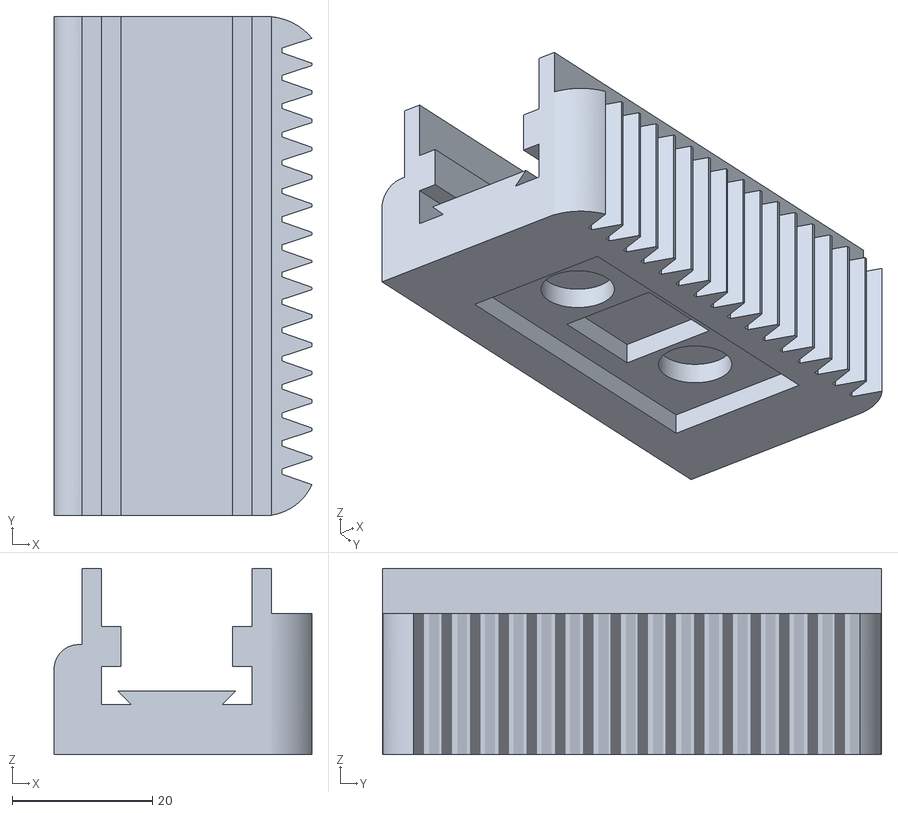
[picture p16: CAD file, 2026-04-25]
3d prints/servo/files/New_Rail.stl
36.7 x 71.0 x 26.5

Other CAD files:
3d prints/servo/files/base.stl
3d prints/2-Axis CNC - 5513594/files/Y-Axis_Carriage_W_Motor.stl
3d prints/servo/files/Rail_v2.0_Servo_HS-85MG_12mm_magnet.stl
3d prints/servo/files/Gear_v2.0_Servo_HS-85MG.stl

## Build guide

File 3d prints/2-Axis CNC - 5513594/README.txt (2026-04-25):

2-Axis CNC by Paragon427 on Thingiverse: https://www.thingiverse.com/thing:5513594

Summary:
I created a 2-Axis CNC to be used as a laser cutter.Here is a link to the instrucable with instructions on assembly and parts needed : https://www.instructables.com/Budget-2-Axis-CNC-Build/I designed this machine with a low budget in mind. I used 20% infill for all printed parts and supports on the pieces with overhangs.

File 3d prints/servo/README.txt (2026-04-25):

Plotter Z axis by Spiritus on Thingiverse: https://www.thingiverse.com/thing:1341835

Summary:
⦁   4x neodym magnets 10mm... V2.0 is 12mm magnets.⦁   Mini 9 gram servo...Or... " V2.0 ( Servo: HS-85MG ) "⦁   servo arm to the gearwheel⦁   glue⦁   Mineral oil or some kind of lubricant⦁   sandpaper + files

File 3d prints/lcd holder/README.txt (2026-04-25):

16x2 LCD Display Stand by Thejustintimer on Thingiverse: https://www.thingiverse.com/thing:1904529

Summary:
After trying to mount my lcd screen rigidly and upright I decided to add a stand to the original design by deisterhold. This design features a 30 degree incline and a method of securing the screen in place which requires no supports. This method uses a bar to slide into position as I'm sure you can work out from the included files.

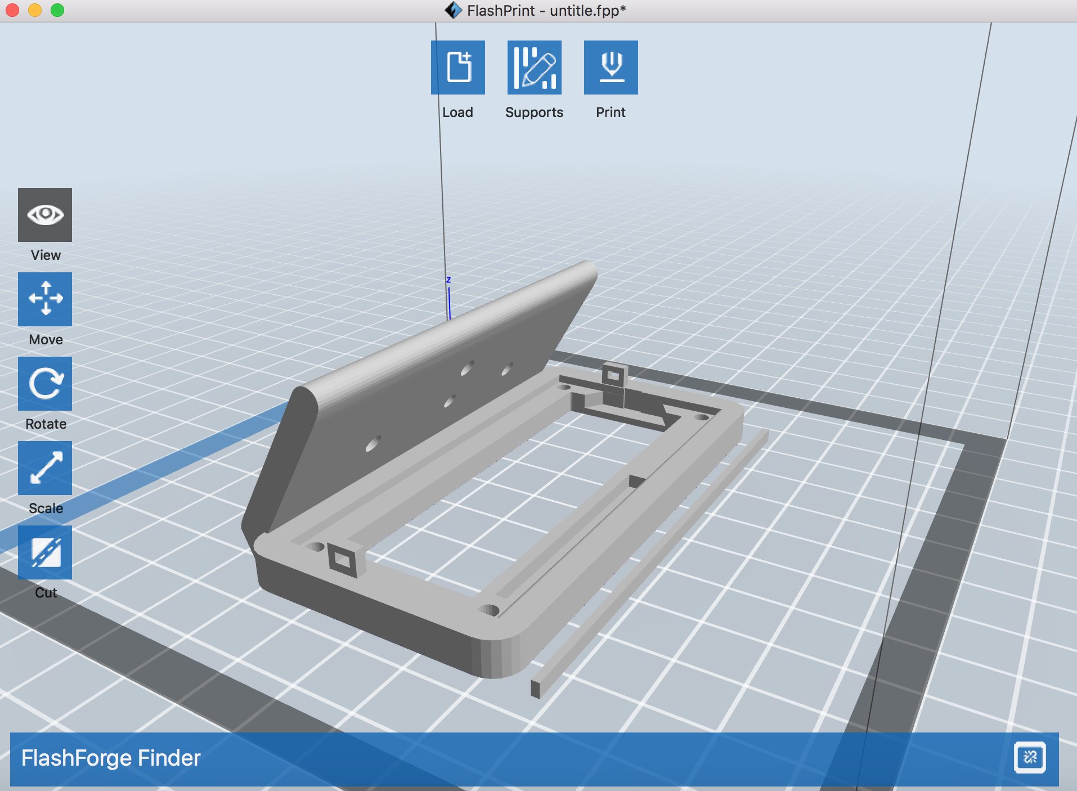
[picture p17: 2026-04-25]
3d prints/lcd holder/images/Screen_Shot_2016-11-21_at_5.59.00_PM.png

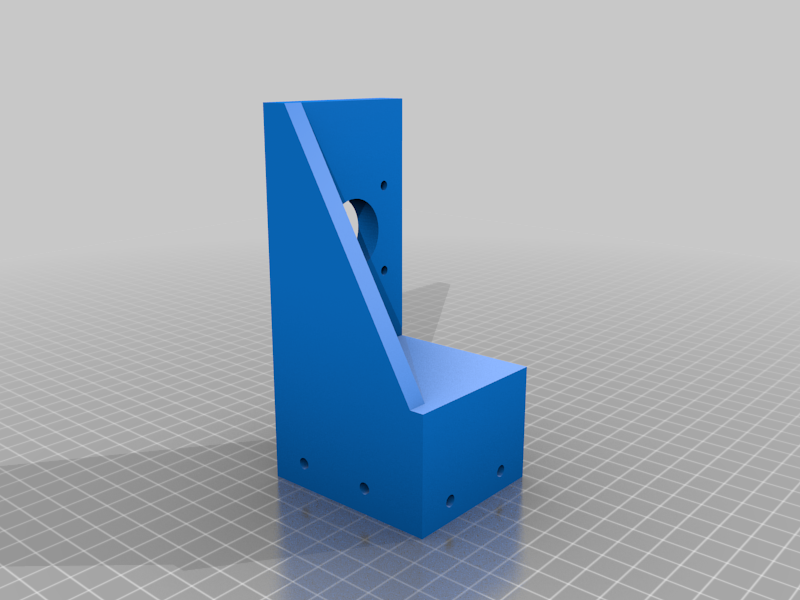
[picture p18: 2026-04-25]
3d prints/2-Axis CNC - 5513594/images/e388011e-67d6-48d2-9319-ce4bdc6c1ae6.png

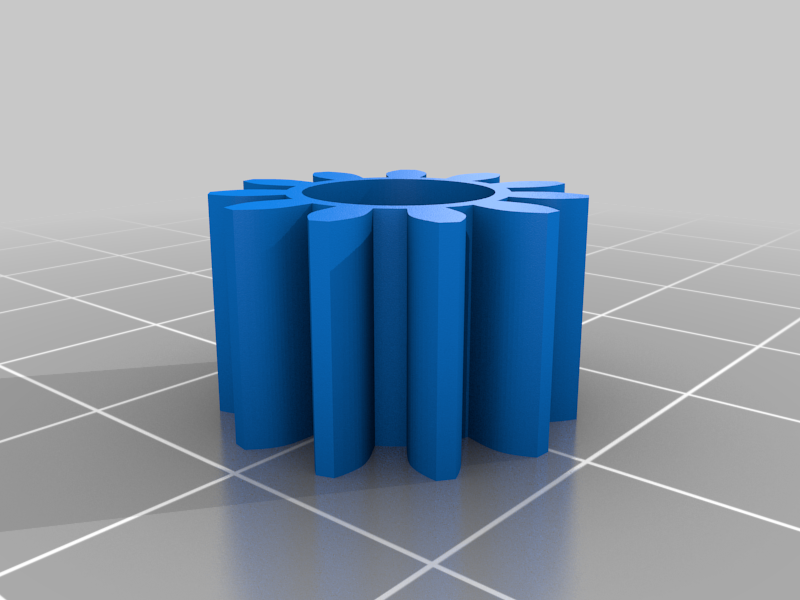
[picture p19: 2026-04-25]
3d prints/servo/images/7f779bc755f02488236bcb452ff18de2.png

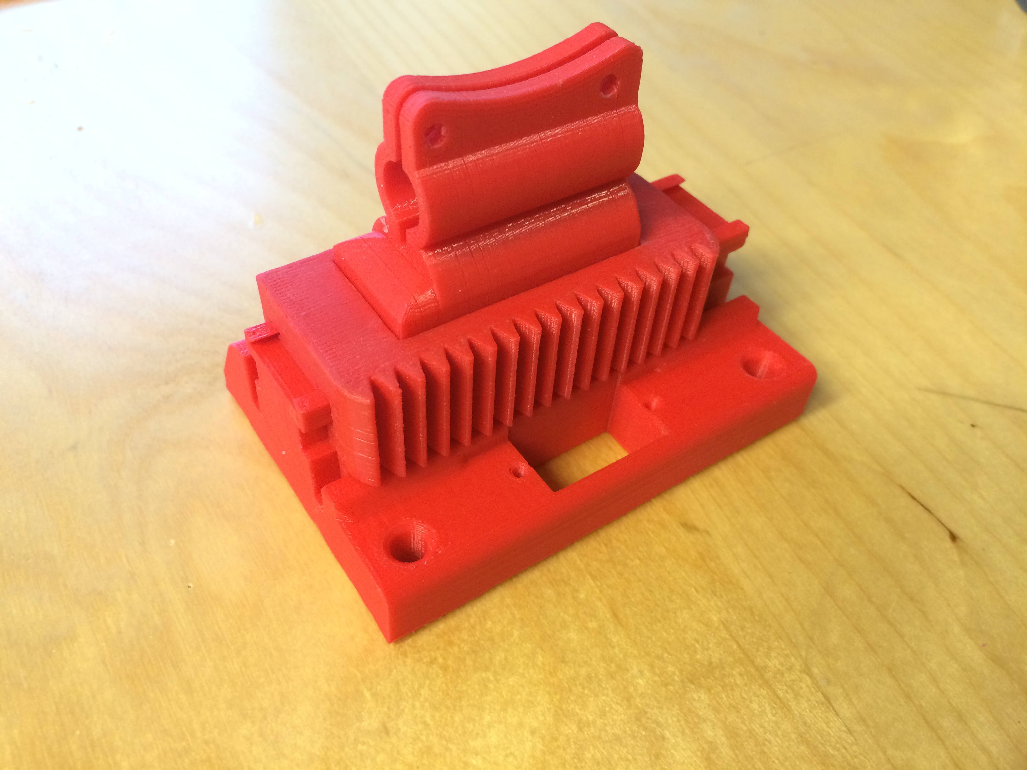
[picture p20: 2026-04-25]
3d prints/servo/images/IMG_0370.JPG

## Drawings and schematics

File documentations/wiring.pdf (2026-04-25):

R2

U2

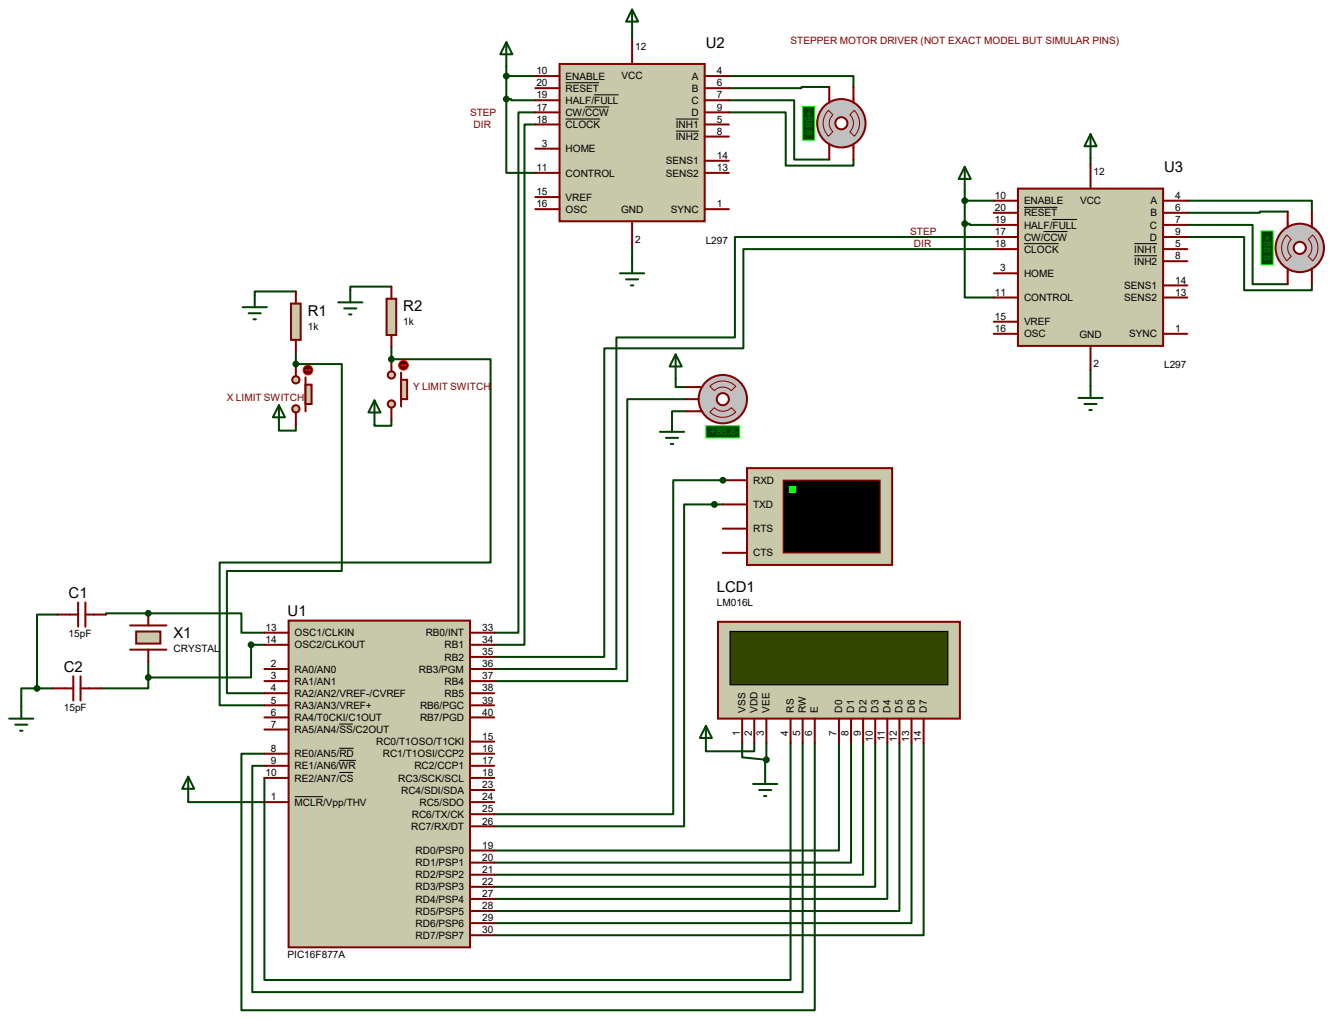
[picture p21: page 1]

STEPPER MOTOR DRIVER (NOT EXACT MODEL BUT SIMULAR PINS)

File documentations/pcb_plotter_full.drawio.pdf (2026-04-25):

# PCB Plotter — How It Works

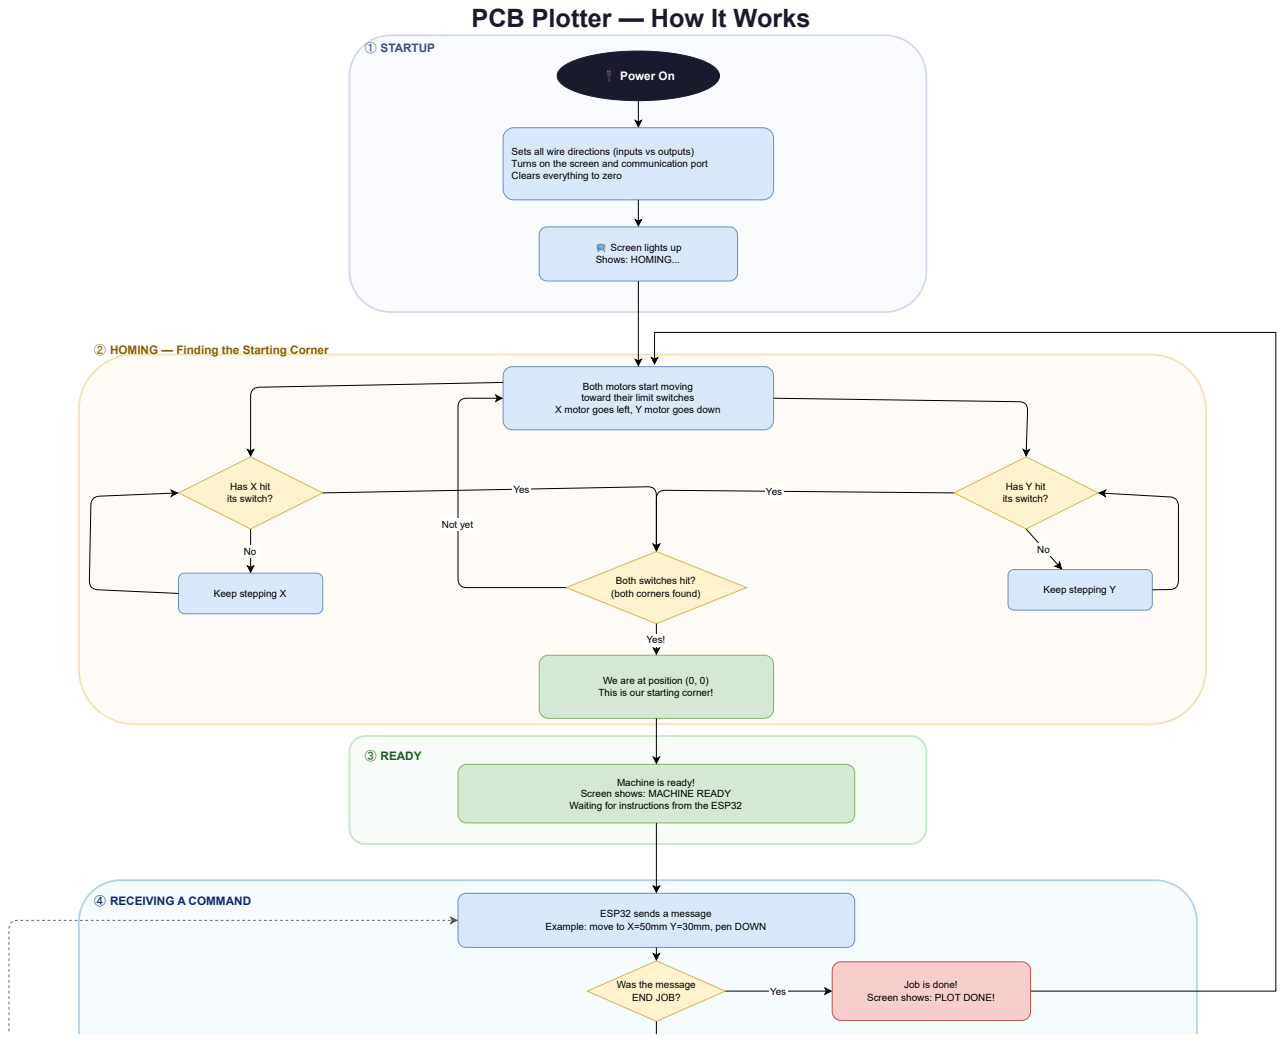
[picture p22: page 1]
① STARTUP; 🔌 Power On; Has X hit its switch?; Keep stepping X; Has Y hit its switch?; Keep stepping Y; ③ READY; ④ RECEIVING A COMMAND; ESP32 sends a message; Yes; Not yet; Yes!

Sets all wire directions (inputs vs outputs)
Turns on the screen and communication port
Clears everything to zero

📺 Screen lights up
Shows: HOMING...

② HOMING — Finding the Starting Corner

Both motors start moving
toward their limit switches
X motor goes left, Y motor goes down

Both switches hit?
(both corners found)

We are at position (0, 0)
This is our starting corner!

Machine is ready!

Screen shows: MACHINE READY
Waiting for instructions from the ESP32

Example: move to X=50mm Y=30mm, pen DOWN

Was the message
END JOB?

Job is done!

Screen shows: PLOT DONE!

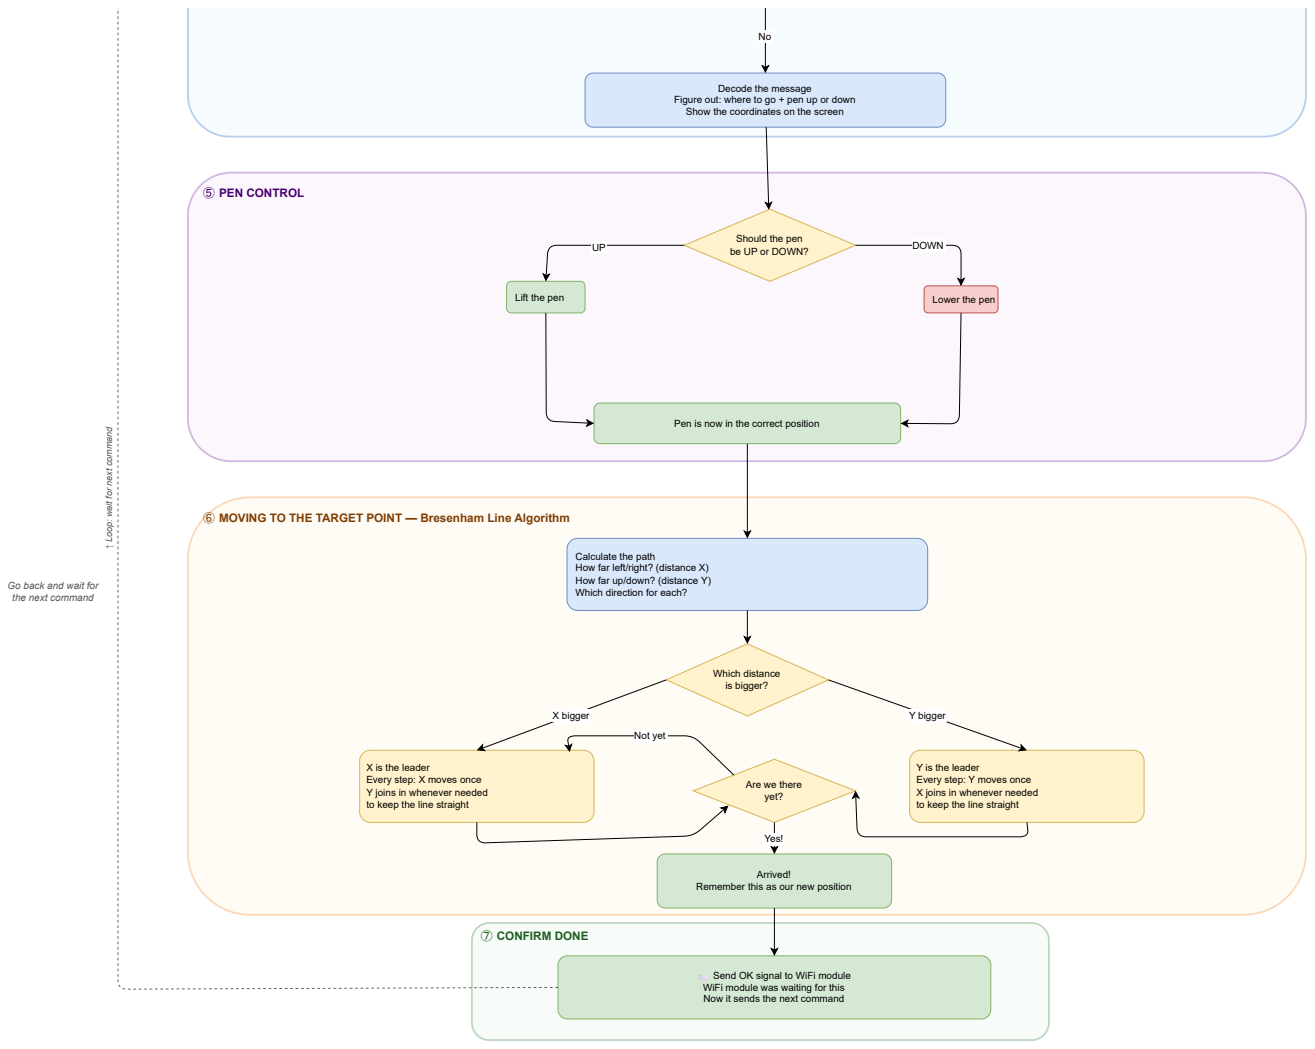
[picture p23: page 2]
⑤ PEN CONTROL; Lift the pen; Lower the pen; Which distance is bigger?; Arrived!; ⑦ CONFIRM DONE; DOWN; X bigger; Y bigger; Not yet

Decode the message

Figure out: where to go + pen up or down
Show the coordinates on the screen

Should the pen
be UP or DOWN?

Pen is now in the correct position

Yes! ↑ Loop: wait for next command

⑥ MOVING TO THE TARGET POINT — Bresenham Line Algorithm

Calculate the path
How far left/right? (distance X)
How far up/down? (distance Y)
Which direction for each?

Go back and wait for
the next command

X is the leader
Every step: X moves once
Y joins in whenever needed
to keep the line straight

Y is the leader
Every step: Y moves once
X joins in whenever needed

Are we there
yet?

Remember this as our new position

📨 Send OK signal to WiFi module
WiFi module was waiting for this
Now it sends the next command

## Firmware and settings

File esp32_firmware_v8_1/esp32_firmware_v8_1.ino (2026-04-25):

// ============================================================
//  CNC PCB Plotter — ESP32 Firmware (v12 — 360° Servo Edition)
//
//  Changes from v12 (position servo) → v12 (360° servo):
//  [SRV-1] SERVO_DOWN_DEG / SERVO_UP_DEG replaced with:
//          SERVO_STOP, SERVO_CW_SPEED, SERVO_CCW_SPEED, SERVO_MOVE_MS
//  [SRV-2] All servo writes now do: spin → delay → stop
//  [SRV-3] setup() parks servo at SERVO_STOP instead of UP angle
//
//  v12 fixes vs v9:
//  [FIX-1] Enforce exactly 14-byte frames (I+6X+6Y+1Z).
//  [FIX-2] Send all 15 bytes in ONE write() call (frame+LF together).
//  [FIX-3] setError() sends "END\n" not println("END").
//  [FIX-4] WAITING_ACK handles 'R' (NAK) from PIC: retransmits the
//          same frame immediately and resets the ACK timeout.
//          PIC sends 'R' when frame validation fails (wrong length,
//          non-digit byte, or pen byte not '1'/'2').
//
//  Architecture (v9):
//  1. Gerber is streamed to Cloud Run via chunked upload.
//  2. Cloud Run saves instructions to a temp file, returns a
//     JSON job ticket: { job_id, total_cmds, total_bytes }.
//  3. ESP32 disconnects from Cloud Run immediately.
//  4. ESP32 fetches instructions in FETCH_CHUNK_SIZE-byte slices
//     (GET /fetch?job=…&offset=…&len=…).  TLS is opened and
//     closed around each fetch — never idle during plotting.
//  5. Each slice is sent to the PIC command-by-command with ACK
//     handshaking.  When all commands are done, ESP32 sends
//     DELETE /job/<id> to clean up the temp file on the server.
//
//  Why this fixes the 3000-command hang:
//  - The TLS connection is NEVER open while waiting for PIC ACKs,
//    so there is no Cloud Run idle-timeout issue.
//  - The response is never read across multiple TLS records in a
//    single pass, avoiding the available()==0 false-done bug.
// ============================================================

#include <WiFi.h>
#include <WebServer.h>
#include <WiFiClientSecure.h>
#include <ESPmDNS.h>
#include <ESP32Servo.h>
#include "secrets.h"   // WIFI_SSID, WIFI_PASSWORD — git-ignored, see secrets.h.example
char currentPenState = '0';  // '0' = unknown, '1' = down, '2' = up

// ------------------------------------------------------------
//  360° Continuous Rotation Servo — GPIO 23
//
//  CALIBRATION GUIDE:
//  1. Flash with SERVO_STOP = 90.  If servo creeps, adjust ±1
//     until it is truly stationary (could be 88–93).
//  2. SERVO_CW_SPEED  = pen-DOWN direction.  Lower = faster CW.
//     SERVO_CCW_SPEED = pen-UP  direction.  Higher = faster CCW.
//  3. SERVO_MOVE_MS: how long to spin before stopping.
//     Start at 300 ms; increase if pen doesn't travel far enough.
// ------------------------------------------------------------
#define SERVO_PIN        23
#define SERVO_STOP       95    // <-- calibrate: truly-stopped PWM value
#define SERVO_CCW_SPEED   70    // pen DOWN  (clockwise)
#define SERVO_CW_SPEED  110   // pen UP    (counter-clockwise)
#define SERVO_MOVE_MS    400   // ms to spin per pen transition

Servo penServo;

// ------------------------------------------------------------
//  Configuration
// ------------------------------------------------------------
// WIFI_SSID / WIFI_PASSWORD are defined in secrets.h (git-ignored).

const char* SERVER_HOST   = "pcb-plotter-server-401310063388.us-central1.run.app";
const int   SERVER_PORT   = 443;
const char* CONVERT_PATH  = "/convert";
const char* FETCH_PATH    = "/fetch";
const char* JOB_BASE_PATH = "/job/";

#define PIC_RX_PIN      16
#define PIC_TX_PIN      17
#define PIC_BAUD        9600    // matches test1.asm SPBRG=25

#define ACK_TIMEOUT_MS  60000
#define HTTP_TIMEOUT_MS 90000
#define HEAP_MIN_BYTES  80000

// Bytes fetched per Cloud Run round-trip.
// 4096 bytes ≈ 372 instructions.  For 3 000 cmds: ~9 fetches.
#define FETCH_CHUNK_SIZE 4096

#define BOUNDARY "----ESP32Boundary7Ma3"

static const char PART_PREAMBLE[] PROGMEM =
    "--" BOUNDARY "\r\n"
    "Content-Disposition: form-data; name=\"gerber\"; filename=\"board.gbr\"\r\n"
    "Content-Type: application/octet-stream\r\n\r\n";

static const char PART_EPILOGUE[] PROGMEM =
    "\r\n--" BOUNDARY "--\r\n";

// ------------------------------------------------------------
//  State machine
// ------------------------------------------------------------
enum PlotState {
    IDLE,
    // — Phase 1: /convert response —
    SENDING,          // wait for HTTP/1.1 status line
    READING_HEADERS,  // read response headers
    READING_JOB,      // read JSON body  { job_id, total_cmds, total_bytes }
    // — Phase 2: chunk-fetch + plot loop —
    FETCH_CONNECT,    // open TLS, send GET /fetch
    FETCH_STATUS,     // read /fetch HTTP status line
    FETCH_HEADERS,    // read /fetch headers
    FETCH_BODY,       // download chunk into chunkBuf
    PLOT_CHUNK,       // send instructions from chunkBuf to PIC one-by-one
    WAITING_ACK,      // wait for 'A' from PIC
    // — Phase 3: cleanup —
    CLEANUP_CONNECT,  // open TLS, send DELETE /job/<id>
    CLEANUP_WAIT,     // drain DELETE response, then close
    // — Terminal —
    DONE,
    PLOT_ERROR
};

// Human-readable names shown in the web UI
static const char* STATE_NAMES[] = {
    "Idle",
    "Waiting for server response",
    "Reading server headers",
    "Reading job info",
    "Connecting to fetch next chunk",
    "Waiting for chunk status",
    "Reading chunk headers",
    "Downloading chunk",
    "Plotting instructions",
    "Waiting for plotter to finish move",
    "Connecting to clean up server file",
    "Deleting temp file on server",
    "Plot complete!",
    "Error"
};

PlotState   plotState = IDLE;
const char* statusMsg = "Idle. Upload a Gerber file to start.";
uint32_t    cmdCount  = 0;
uint32_t    totalCmds = 0;
bool        plotBusy  = false;
bool        uploadError = false;

// Job ticket received from /convert
char     jobId[36]         = "";
uint32_t fetchOffset       = 0;
uint32_t fetchTotalBytes   = 0;

// Per-request tracking (reused for convert, fetch, delete)
uint32_t bodyExpected = 0;   // Content-Length of current response
uint32_t bodyRead     = 0;   // bytes consumed so far

// Chunk buffer: holds one FETCH_CHUNK_SIZE slice + leftover from prev chunk
static char     chunkBuf[FETCH_CHUNK_SIZE + 64];
static uint16_t chunkLen = 0;   // valid bytes in chunkBuf
static uint16_t chunkPos = 0;   // read cursor inside chunkBuf

// Partial instruction line carried across chunk boundaries
static char    leftover[32] = "";
static uint8_t leftoverLen  = 0;

// Line assembly for PIC commands
char    lineBuf[32];
uint8_t lineIdx = 0;

unsigned long ackStart = 0;

WiFiClientSecure tlsClient;
WebServer        server(80);

// ------------------------------------------------------------
//  Debug log  (shown live in the web UI, last LOG_LINES msgs)
// ------------------------------------------------------------
#define LOG_LINES 12
#define LOG_WIDTH 80

static char    logBuf[LOG_LINES][LOG_WIDTH + 1];
static uint8_t logNext    = 0;   // next write slot  [0..LOG_LINES-1]
static uint8_t logCount   = 0;   // entries present, capped at LOG_LINES
static bool    logWrapped = false;

void dbgLog(const char* fmt, ...) {
    char tmp[LOG_WIDTH + 1];
    va_list ap;
    va_start(ap, fmt);
    vsnprintf(tmp, sizeof(tmp), fmt, ap);
    va_end(ap);

    strncpy(logBuf[logNext], tmp, LOG_WIDTH);
    logBuf[logNext][LOG_WIDTH] = '\0';
    logNext = (logNext + 1) % LOG_LINES;

    if (!logWrapped) {
        if (logCount < LOG_LINES) logCount++;
        else                      logWrapped = true;
    }
    Serial.printf("[LOG] %s\n", tmp);
}

// ------------------------------------------------------------
//  360° servo helper — spin for SERVO_MOVE_MS then stop
// ------------------------------------------------------------

void servoPenDown() {
    if (currentPenState == '1') return;  // already down, don't move
    penServo.write(SERVO_CCW_SPEED);
    delay(SERVO_MOVE_MS);
    penServo.write(SERVO_STOP);
    currentPenState = '1';
    Serial.println("[SERVO] DOWN (CW)");
}

void servoPenUp() {
    if (currentPenState == '2') return;  // already up, don't move
    penServo.write(SERVO_CW_SPEED);
    delay(SERVO_MOVE_MS);
    penServo.write(SERVO_STOP);
    currentPenState = '2';
    Serial.println("[SERVO] UP (CCW)");
}

// ------------------------------------------------------------
//  Web UI HTML  (served from flash)
// ------------------------------------------------------------
static const char INDEX_HTML[] PROGMEM = R"rawhtml(
<!DOCTYPE html>
<html lang="en">
<head>
  <meta charset="UTF-8">
  <meta name="viewport" content="width=device-width,initial-scale=1">
  <title>PCB Plotter</title>
  <style>
    *{box-sizing:border-box}
    body{font-family:system-ui,sans-serif;max-width:600px;margin:44px auto;
         padding:0 16px;background:#f0f4f8;color:#1a202c}
    h2{color:#1a237e;margin:0 0 16px}
    .card{background:#fff;border-radius:10px;padding:18px 20px;
          box-shadow:0 2px 6px rgba(0,0,0,.1);margin-bottom:16px}
    label{font-size:.85rem;color:#555;font-weight:600}
    input[type=file]{display:block;margin:10px 0 14px;font-size:.9rem;width:100%}
    button{background:#1565C0;color:#fff;border:none;padding:11px 0;
           font-size:1rem;border-radius:6px;cursor:pointer;width:100%;
           letter-spacing:.3px}
    button:hover{background:#0d47a1}
    button:disabled{background:#90a4ae;cursor:not-allowed}

    /* phase badge */
    #phase{display:inline-block;font-size:.72rem;font-weight:700;
           text-transform:uppercase;letter-spacing:.6px;padding:3px 9px;
           border-radius:12px;background:#e3f2fd;color:#1565c0;margin-bottom:8px}
    #phase.ok {background:#e8f5e9;color:#2e7d32}
    #phase.err{background:#ffebee;color:#c62828}

    /* status line */
    #status{padding:10px 13px;border-radius:6px;background:#f5f5f5;
            min-height:38px;font-family:monospace;font-size:.88rem;
            white-space:pre-wrap;line-height:1.5}
    #status.ok  {background:#e8f5e9;color:#1b5e20}
    #status.err {background:#ffebee;color:#b71c1c}
    #status.busy{background:#fff8e1;color:#bf360c}

    /* progress bar */
    #bar-wrap{display:none;margin-top:10px;background:#e0e0e0;
              border-radius:6px;overflow:hidden;height:10px}
    #bar{height:10px;background:#1565C0;width:0%;transition:width .35s}
    #bar.done{background:#43a047}

    /* stats row */
    #stats{display:none;gap:10px;flex-wrap:wrap;margin-top:12px}
    .stat{flex:1;min-width:100px;background:#f5f5f5;border-radius:6px;
          padding:7px 10px;text-align:center;font-size:.8rem;color:#555}
    .stat b{display:block;font-size:1.05rem;color:#1565C0;margin-bottom:2px}

    /* debug log */
    .log-label{font-size:.75rem;font-weight:700;color:#666;
               text-transform:uppercase;letter-spacing:.5px;margin-bottom:6px}
    #log-box{background:#1e1e2e;color:#cdd6f4;font-family:monospace;
             font-size:.76rem;padding:10px 12px;border-radius:8px;
             min-height:130px;max-height:220px;overflow-y:auto;
             white-space:pre-wrap;line-height:1.55}
    .ll-err {color:#f38ba8}
    .ll-ok  {color:#a6e3a1}
    .ll-warn{color:#f9e2af}
    .ll-info{color:#89dceb}
  </style>
</head>
<body>
  <h2>&#x1F9F0; CNC PCB Plotter</h2>

  <!-- upload card -->
  <div class="card">
    <form id="f" enctype="multipart/form-data">
      <label>Gerber file (.gbr / .gtl / .grb)</label>
      <input type="file" id="g" accept=".gbr,.gtl,.gbp,.ger,.grb" required>
      <button type="submit" id="btn">&#9658;&nbsp;Upload &amp; Plot</button>
    </form>
  </div>

  <!-- status card -->
  <div class="card">
    <div id="phase">Idle</div>
    <div id="status">Ready. Select a Gerber file and press Upload &amp; Plot.</div>
    <div id="bar-wrap"><div id="bar"></div></div>
    <div id="stats">
      <div class="stat"><b id="s-cmd">—</b>Commands sent</div>
      <div class="stat"><b id="s-total">—</b>Total commands</div>
      <div class="stat"><b id="s-kb">0</b>KB fetched</div>
      <div class="stat"><b id="s-state">—</b>State #</div>
    </div>
  </div>

  <!-- debug log card -->
  <div class="card">
    <div class="log-label">&#x1F50D; Live Debug Log</div>
    <div id="log-box"><span style="color:#585b70">Waiting for activity…</span></div>
  </div>

<script>
const st    = document.getElementById('status');
const bar   = document.getElementById('bar');
const bw    = document.getElementById('bar-wrap');
const btn   = document.getElementById('btn');
const ph    = document.getElementById('phase');
const lb    = document.getElementById('log-box');
const stats = document.getElementById('stats');
let poll = null;

function colorLine(s) {
  const lo = s.toLowerCase();
  if (lo.includes('error') || lo.includes('failed') || lo.includes('timeout') || lo.includes('crash'))
    return `<div class="ll-err">${s}</div>`;
  if (lo.includes('done') || lo.includes('complete') || lo.includes('deleted') || lo.includes('plot done'))
    return `<div class="ll-ok">${s}</div>`;
  if (lo.includes('warn') || lo.includes('skip'))
    return `<div class="ll-warn">${s}</div>`;
  return `<div class="ll-info">${s}</div>`;
}

function pct(a, b) { return b > 0 ? Math.round(a * 100 / b) : 0; }

function updateUI(j) {
  ph.textContent = j.state_name || 'Unknown';
  ph.className   = j.done ? 'ok' : (j.error ? 'err' : '');

  st.className   = j.done ? 'ok' : (j.error ? 'err' : 'busy');
  st.textContent = j.msg || '';

  bw.style.display = 'block';
  let p = 0;
  if (j.total > 0)           p = pct(j.sent, j.total);
  else if (j.total_bytes > 0) p = pct(j.fetched_bytes, j.total_bytes);
  bar.style.width = p + '%';
  bar.className   = j.done ? 'done' : '';

  stats.style.display = 'flex';
  document.getElementById('s-cmd').textContent   = j.sent   !== undefined ? j.sent   : '—';
  document.getElementById('s-total').textContent = j.total  > 0           ? j.total  : '—';
  document.getElementById('s-kb').textContent    = j.fetched_bytes > 0
      ? (j.fetched_bytes / 1024).toFixed(1) : '0';
  document.getElementById('s-state').textContent = j.state !== undefined ? j.state : '—';

  if (j.log && j.log.length > 0) {
    lb.innerHTML = j.log.map(colorLine).join('');
    lb.scrollTop = lb.scrollHeight;
  }

  if (j.done || j.error) {
    clearInterval(poll); poll = null;
    btn.disabled = false;
    if (j.done) bar.style.width = '100%';
  }
}

function startPoll() {
  bw.style.display = 'block';
  bar.className    = '';
  poll = setInterval(async () => {
    try {
      const r = await fetch('/api/status');
      const j = await r.json();
      updateUI(j);
    } catch(e) { /* ignore transient WiFi hiccups */ }
  }, 1500);
}

document.getElementById('f').addEventListener('submit', async e => {
  e.preventDefault();
  const file = document.getElementById('g').files[0];
  if (!file) return;
  if (poll) { clearInterval(poll); poll = null; }

  btn.disabled     = true;
  st.className     = 'busy';
  ph.className     = '';
  ph.textContent   = 'Uploading';
  st.textContent   = 'Uploading ' + file.name +
                     ' (' + (file.size/1024).toFixed(1) + ' KB)…';
  bar.style.width  = '0%';
  bar.className    = '';
  bw.style.display = 'block';
  lb.innerHTML     = '<span style="color:#585b70">Starting upload…</span>';

  const fd = new FormData();
  fd.append('gerber', file);
  try {
    const r = await fetch('/upload', { method:'POST', body:fd });
    const t = await r.text();
    if (!r.ok) {
      st.className   = 'err';
      ph.className   = 'err';
      ph.textContent = 'Upload failed';
      st.textContent = t;
      btn.disabled   = false;
      return;
    }
    ph.textContent = 'Processing';
    st.textContent = t;
    startPoll();
  } catch(err) {
    st.className   = 'err';
    ph.className   = 'err';
    ph.textContent = 'Error';
    st.textContent = 'Upload error: ' + err.message;
    btn.disabled   = false;
  }
});
</script>
</body>
</html>
)rawhtml";

// ------------------------------------------------------------
//  Low-level helpers
// ------------------------------------------------------------
void closeTls() {
    if (tlsClient.connected()) {
        tlsClient.flush();
        tlsClient.stop();
        delay(50);
    }
}

void setError(const char* msg) {
    statusMsg = msg;
    plotState = PLOT_ERROR;
    plotBusy  = false;
    closeTls();
    Serial2.print("END\n");   // bare LF only — println sends CR+LF
    dbgLog("ERROR: %s", msg);
}

void sendProgmem(const char* pgm, size_t len) {
    char buf[65];
    size_t off = 0;
    while (off < len) {
        size_t n = min((size_t)64, len - off);
        memcpy_P(buf, pgm + off, n);
        buf[n] = '\0';
        tlsClient.print(buf);
        off += n;
    }
}

// Send one HTTP/1.1 chunked-encoding frame
void sendChunk(const uint8_t* data, size_t len) {
    char hdr[10];
    snprintf(hdr, sizeof(hdr), "%X\r\n", (unsigned)len);
    tlsClient.print(hdr);
    if (len) tlsClient.write(data, len);
    tlsClient.print("\r\n");
}

bool openTls() {
    closeTls();
    tlsClient.setInsecure();
    tlsClient.setTimeout(HTTP_TIMEOUT_MS / 1000);
    return tlsClient.connect(SERVER_HOST, SERVER_PORT);
}
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
void loop() {
    server.handleClient();

    if (plotBusy) {
        runPlotMachine();
    }

    // Log any unexpected bytes from PIC when not waiting for an ACK
    if (plotState != WAITING_ACK && Serial2.available()) {
        char c = (char)Serial2.read();
        Serial.printf("[PIC unsolicited] 0x%02X '%c'\n",
                      (uint8_t)c, c >= 0x20 ? c : '?');
    }
}

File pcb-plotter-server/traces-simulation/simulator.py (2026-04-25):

"""
CNC PCB Plotter — Python Simulator  (mirrors PIC16F877A v10 firmware logic)
============================================================================
Reads a TXT file of plotter commands in the protocol format:
    I XXXX YYYY Z LF
  where XXXX/YYYY are 4-digit ASCII decimal mm values (zero-padded)
  and Z is '1' (pen DOWN) or '2' (pen UP).
  A line containing just "END" signals the end of the job.

The script faithfully re-implements:
  • CONV_X / CONV_Y  — ASCII digit → mm → steps  (×25 exact)
  • BRESENHAM        — 16-bit Bresenham line algorithm with correct
                       borrow propagation (v10-FIX-8, v10-FIX-9)
  • Servo state      — pen only changes when state differs from previous

Usage:
    python cnc_plotter_sim.py commands.txt [--output plot.png] [--scale 2]

The script produces:
  1. A matplotlib window showing the traced image in real time (if --live)
     OR a saved PNG (default).
  2. A summary printed to stdout with step counts and move statistics.

Protocol reminder (from firmware header):
    Frame : I XXXX YYYY Z LF   (10 chars + LF = 11 bytes)
    BUF[0]   = 'I'
    BUF[1..4] = X digits (mm, 4 ASCII decimal digits, zero-padded)
    BUF[5..8] = Y digits (mm, 4 ASCII decimal digits, zero-padded)
    BUF[9]    = pen state ('1'=down, '2'=up)
    LF (0x0A) = terminator, NOT stored in BUF
    CR (0x0D) = silently discarded

Machine constants (mirrored from firmware):
    STEPS_PER_MM = 25   (200 steps/rev ÷ 8 mm lead, T8 screw, NEMA17)
    Max X = 200 mm  →  5000 steps
    Max Y = 180 mm  →  4500 steps
"""

import sys
import argparse
import math
import matplotlib
import matplotlib.pyplot as plt
import matplotlib.patches as mpatches

# ---------------------------------------------------------------------------
#   Machine constants  (match firmware EQU values)
# ---------------------------------------------------------------------------
STEPS_PER_MM = 25  # 200 steps/rev / 8 mm lead — exact integer
MAX_X_MM = 200
MAX_Y_MM = 180
MAX_X_STEPS = MAX_X_MM * STEPS_PER_MM  # 5000
MAX_Y_STEPS = MAX_Y_MM * STEPS_PER_MM  # 4500


# ===========================================================================
#   CONV_X / CONV_Y
#   Mirrors the PIC's BCD-style digit extraction and ×25 multiply.
#   Input : 4-char ASCII string, e.g. "0127"
#   Output: integer step count (16-bit range)
# ===========================================================================
def conv_mm_to_steps(digits: str) -> int:
    """
    Reproduce CONV_X / CONV_Y from firmware.
    digits must be exactly 4 ASCII decimal characters '0'..'9'.
    Each char is ANDed with 0x0F to strip the ASCII offset (as firmware does).
    Formula: steps = (d3*1000 + d2*100 + d1*10 + d0) * STEPS_PER_MM
    Result clamped to 16-bit (0..65535) — firmware uses 16-bit registers.
    """
    if len(digits) != 4:
        raise ValueError(f"Expected 4 digit chars, got {len(digits)!r}")
    return int(digits)  # app.py already sends steps (pre-multiplied by 25)


# ===========================================================================
#   PARSE_LINE
#   Mirrors RECEIVE_LINE + PARSE_AND_DISPLAY from firmware.
#   Returns (x_steps, y_steps, pen_down: bool) or None for END.
# ===========================================================================
def parse_line(raw: str):
    """
    Parse one command line.  Returns:
      None               — if line is "END" sentinel
      (xtgt, ytgt, pen_down)  — int steps, int steps, bool
    Raises ValueError on malformed lines.
    """
    # Strip CR and LF (firmware silently discards CR, stops at LF)
    line = raw.rstrip("\r\n")
    if not line:
        return "SKIP"

    # END sentinel check (firmware checks BUF[0..2] == 'E','N','D')
    if line.upper() == "END":
        return None

    # Frame validation: must start with 'I' and be exactly 10 chars
    if len(line) < 10 or line[0] != "I":
        raise ValueError(f"Bad frame (expected 'I' + 9 chars): {line!r}")

    x_digits = line[1:5]  # BUF[1..4]
    y_digits = line[5:9]  # BUF[5..8]
    pen_char = line[9]  # BUF[9]

    xtgt = conv_mm_to_steps(x_digits)
    ytgt = conv_mm_to_steps(y_digits)

    if pen_char == "1":
        pen_down = True
    elif pen_char == "2":
        pen_down = False
    else:
        raise ValueError(f"Unknown pen state {pen_char!r}, expected '1' or '2'")

    return (xtgt, ytgt, pen_down)


# ===========================================================================
#   BRESENHAM  (v10 — correct 16-bit borrow propagation)
#   Mirrors the full BRESENHAM / BRES_LOOP / BRES_CALC subroutines.
#
#   Instead of toggling physical GPIO pins we collect (x, y) waypoints
#   that are later plotted.
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

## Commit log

2026-03-03 Add initial Dockerfile, app.py, and requirements.txt for PCB plotter server
2026-03-22 still testing
    [test_square.gbr]
2026-04-25 Update plotter server: steps-based output, pad fills, job-based fetch
    - Rewrite Gerber-to-protocol conversion: integer-step output (mm x 400),
    pen-width-aware aperture pad filling (C/R/O), X-mirror, configurable
    trace passes, and bounds-check against MAX_X/Y.
    - Replace single-shot /convert response with job-based flow: /convert
    returns job_id + total_cmds/bytes; /fetch streams chunks by offset/len;
    DELETE /job/<id> cleans up. Adds UUID-hex job-id validation.
    - Add .gitignore (Python, .venv, IDE, OS, secrets/env files).
    - Untrack .vscode/settings.json (now ignored).
    - Add traces-simulation/ (firmware-mirroring Python plotter simulator
    plus sample cloud output and result render).
    - D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
    [test_square.gbr]
2026-04-25 Restructure repo: include all project folders, externalize WiFi creds
    - Promote git root from pcb-plotter-server/ to project root so all
    related folders live in one repo (3d prints, asm, documentations,
    esp32_firmware_v8_1, pcb-plotter-server, simulations).
    - Cloud Run server files moved under pcb-plotter-server/ (renames
    preserved by git).
    - ESP32 firmware: extract WIFI_SSID / WIFI_PASSWORD to secrets.h
    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
    [Gear.stl, Gear_v2.0_Servo_HS-85MG.stl, LCD_Screen_Stand_v2.stl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]
2026-04-25 Rename project from DIY PCB Plotter to PCB ETCHER
